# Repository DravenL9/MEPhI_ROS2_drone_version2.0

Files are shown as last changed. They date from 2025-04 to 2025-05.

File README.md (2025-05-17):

# MEPhI_ROS2_drone

**MEPhI_ROS2_drone** - это двухколесный робот с открытым исходным кодом, разработанный для образовательных целей командой студентов из НИЯУ МИФИ. MEPhI_ROS2_drone полностью интегрирован с ROS2 и является отличной базовой платформой для плавного введения в ROS2. Благодаря открытому коду и исходным файлам 3D моделей любой желающий может модифицировать и настроить робота в соответствии со своими требованиями.

*Данный проект является форком проекта [Andino](https://github.com/Ekumen-OS/andino), ПО, конструкция и электрическая схема которого были доработаны под наши требования.

<p align="center">
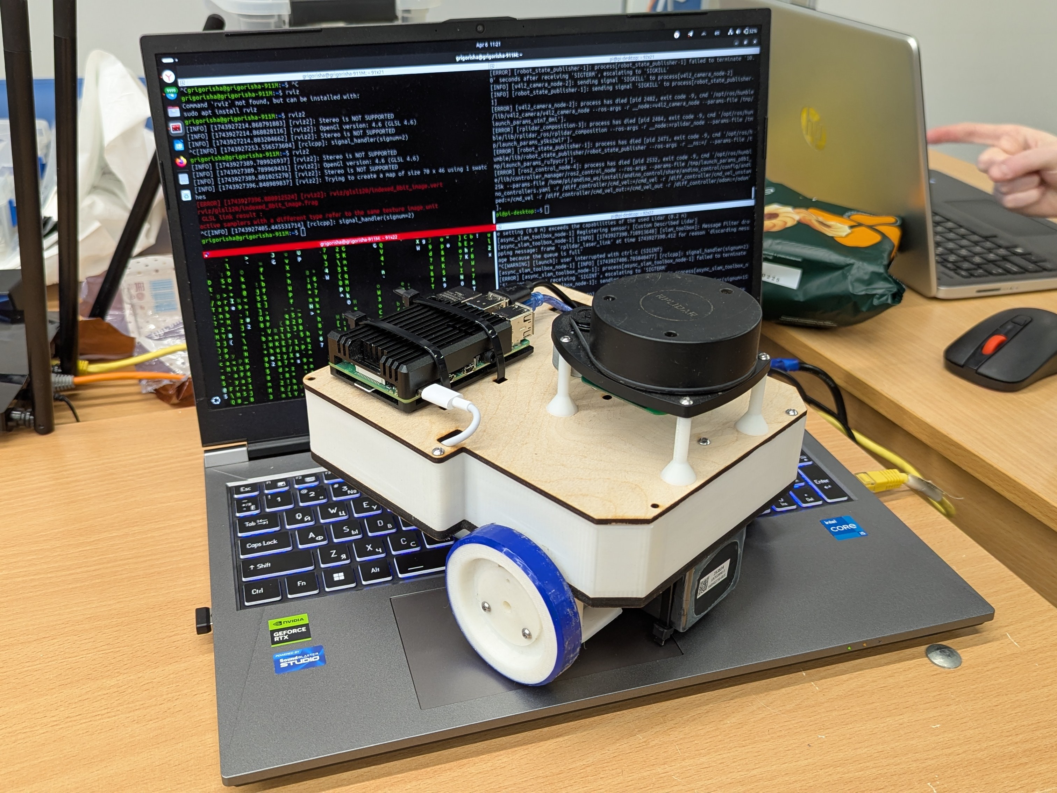
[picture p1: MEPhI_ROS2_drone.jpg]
  
</p>

## Описание проекта
- [`3D`](./3D): 3D модели деталей и сборки робота, также содержит `.stl` для 3D печати и `.dxf` для лазерной резки
- [`schematic`](./schematic): электрическая схема робота и инструкция по ее сборке
- [`MEPhI_ROS2_drone_hardware`](./andino_hardware): содержит инструкцию по сборке `MEPhI_ROS2_drone` и перечень используемого оборудования
- [`MEPhI_ROS2_drone_firmware`](./andino_firmware): содержит код отладочной платы Arduino UNO R3 для сопряжения с raspberry pi 4 и инструкцию по его заливке на плату
- [`MEPhI_ROS2_drone_bringup`](./andino_bringup): содержит файлы запуска для старта всех связанных драйверов и нод, которые будут использоваться в роботе
- [`MEPhI_ROS2_drone_description`](./andino_description): содержит описание робота в формате `.urdf`
- [`MEPhI_ROS2_drone_base`](./andino_base): это программно-аппаратный модуль проекта, который обеспечивает связь с микроконтроллером для управления моторами и предоставляет утилиты для отладки
- [`MEPhI_ROS2_drone_control`](./andino_control/): запускает [controller_manager](https://control.ros.org/humble/doc/ros2_control/controller_manager/doc/userdoc.html) вместе с [ros2 controllers](https://control.ros.org/master/doc/ros2_controllers/doc/controllers_index.html): [diff_drive_controller](https://control.ros.org/master/doc/ros2_controllers/diff_drive_controller/doc/userdoc.html) и [joint_state_broadcaster](https://control.ros.org/master/doc/ros2_controllers/joint_state_broadcaster/doc/userdoc.html)
- [`MEPhI_ROS2_drone_slam`](./andino_slam/): обеспечивает работу `SLAM` (одновременная локализация и построение карты)
- [`MEPhI_ROS2_drone_navigation`](./andino_navigation/): стек навигации, основанный на `Nav2`

## Видеоматериалы работы

### Отображение LaserScan в rviz2

LaserScan (https://youtu.be/dyld3nLJG04)

### Построение карты в ручном режиме

LaserScan (https://youtu.be/CHcgCHSs_-0)

### Автономное движение по карте

LaserScan (https://youtu.be/ocD7KzcdPOI)

## Сборка MEPhI_ROS2_drone

- Сборка конструкции робота подробно описана в [`andino_hardware`](./andino_hardware/)
- Сборка электрической схемы подробно описана в [`schematic`](./schematic/)

## Установка Ubuntu 22.04 на Raspberry Pi

Для работы MEPhI_ROS2_drone на Raspberry Pi 4B необходимо установить и настроить Ubuntu 22.04 LTS.

### Шаг 1: Загрузка и запись образа
1. Перейдите на сайт [https://ubuntu.com/download/raspberry-pi](https://ubuntu.com/download/raspberry-pi)
2. Выберете руководство по установке Ubuntu Desktop

### Шаг 2: Начальная настройка
1. Вставьте карту MicroSD в Raspberry Pi и подключите кабель питания USB-C 
2. Подключите монитор и клавиатуру
3. Проследуйте указаниям на экране
4. Запустите терминал и введите
```
sudo apt update && sudo apt upgrade -y
```
5. Проверьте версию Ubuntu (ожидаемый вывод: `Ubuntu 22.04 LTS`):
```
lsb_release -a
```
6. Проверьте подключение к интернету:
```
ping google.com
```

## Настройка USB портов

Назначьте фиксированные имена USB-портам для стабильного распознавания устройств в ROS2.

1. Подключите Arduino UNO R3 и RPLIDAR A1 к Raspberry Pi
2. Просмотрите подключенные USB-устройства:
```
ls -l /dev/ttyUSB*
```
Пример вывода:
```
crw-rw---- 1 root dialout 188, 0 Apr 06 03:10 /dev/ttyUSB0
crw-rw---- 1 root dialout 188, 1 Apr 06 03:10 /dev/ttyUSB1
```
3. Определите устройства:
 - Отключите RPLIDAR и снова выполните ls -l /dev/ttyUSB*. Исчезнувшее устройство — RPLIDAR
 - Повторите для Arduino
 - Пример: `/dev/ttyUSB0 = Arduino`, `/dev/ttyUSB1 = RPLIDAR`

4. Получите идентификаторы устройств:
```
udevadm info --name=/dev/ttyUSB0 --attribute-walk | grep -i "serial\|vendor"
```
Пример для Arduino:
```
ATTRS{serial}=="A1234567"
ATTRS{vendor}=="Arduino"
```
Пример для RPLIDAR:
```
ATTRS{serial}=="B7890123"
ATTRS{vendor}=="SLAMTEC"
```
5. Создайте правила udev:
 - Отредактируйте файл правил:
 ```
 sudo nano /etc/udev/rules.d/99-usb-serial.rules
 ```
 - Добавьте (замените serial на ваши значения):
```
SUBSYSTEM=="tty", ATTRS{serial}=="A1234567", SYMLINK+="ttyUSB_ARDUINO"
SUBSYSTEM=="tty", ATTRS{serial}=="B7890123", SYMLINK+="ttyUSB_LIDAR"
```
- Сохраните (Ctrl+O, Enter, Ctrl+X)

6. Перезагрузите правила:
```
sudo udevadm control --reload-rules
sudo udevadm trigger
```
7. Проверьте новые имена:
```
ls -l /dev/ttyUSB*
```
Ожидаемый вывод:
```
lrwxrwxrwx 1 root root 7 Apr 06 03:15 /dev/ttyUSB_ARDUINO -> ttyUSB0
lrwxrwxrwx 1 root root 7 Apr 06 03:15 /dev/ttyUSB_LIDAR -> ttyUSB1
```

## Прошивка отладочной платы Arduino UNO R3

Следуйте руководству в [`MEPhI_ROS2_drone_firmware`](./andino_firmware)

## Установка ROS2 Humble

### Шаг 1: Установка зависимостей
1. Настройте локализацию:
```
sudo apt update && sudo apt install -y locales
sudo locale-gen en_US en_US.UTF-8
sudo update-locale LC_ALL=en_US.UTF-8 LANG=en_US.UTF-8
export LANG=en_US.UTF-8
```
2. Добавьте репозиторий ROS2:
```
sudo apt install -y software-properties-common
sudo add-apt-repository universe
sudo apt update && sudo apt install -y curl gnupg lsb-release
sudo curl -sSL https://raw.githubusercontent.com/ros/rosdistro/master/ros.key -o /usr/share/keyrings/ros-archive-keyring.gpg
echo "deb [arch=$(dpkg --print-architecture) signed-by=/usr/share/keyrings/ros-archive-keyring.gpg] http://packages.ros.org/ros2/ubuntu $(lsb_release -cs) main" | sudo tee /etc/apt/sources.list.d/ros2.list > /dev/null
```
### Шаг 2: Установка ROS2
1. Установите ROS2 Humble Desktop:
```
sudo apt update
sudo apt install -y ros-humble-desktop
```
2. Установите инструменты разработки:
```
sudo apt install -y python3-colcon-common-extensions python3-rosdep python3-vcstool
```
3. Инициализируйте rosdep:
```
sudo rosdep init
rosdep update
```
4. Настройте окружение:
```
echo "source /opt/ros/humble/setup.bash" >> ~/.bashrc
source ~/.bashrc
```

## Сборка рабочего пространства MEPhI_ROS2_drone
### Шаг 1: Клонирование репозитория
1. Создайте рабочее пространство:
```
mkdir -p ~/MEPhI_ROS2_drone_ws/src
cd ~/MEPhI_ROS2_drone_ws/src
```
2. Склонируйте репозиторий:
```
git clone -b humble https://github.com/Muhamedli/MEPhI_ROS2_drone.git
```
### Шаг 2: Установка зависимостей
1. Установите зависимости ROS:
```
cd ~/MEPhI_ROS2_drone_ws
rosdep install --from-paths src --ignore-src -r -y
```
### Шаг 3: Сборка
1. Соберите проект:
```
colcon build
```
2. Подгрузите окружение:
```
echo "source ~/MEPhI_ROS2_drone_ws/install/setup.bash" >> ~/.bashrc
source ~/MEPhI_ROS2_drone_ws/install/setup.bash
```

## Настройка и запуск SLAM
SLAM позволяет роботу строить карту неизвестной среды и одновременно определять свое местоположение. В этом разделе используется пакет MEPhI_ROS2_drone_slam с алгоритмом Cartographer.

### Шаг 1: Запуск базовых нод
1. Запустите базовые ноды робота:
```
ros2 launch andino_bringup andino_robot.launch.py
```
Это активирует ноды для работы с двигателями и лидаром.

2. Проверьте доступные топики:
```
ros2 topic list
```
Ожидаемые топики:
- `/odom`: данные одометрии
- `/scan`: данные лидара

### Шаг 2: Запуск SLAM
1. Запустите SLAM:
```
ros2 launch andino_slam slam_toolbox_online_async.launch.py
```
2. Запустите rviz:
```
rviz2
```
3. Управляйте роботом для построения карты:
 - В новом терминале запустите телеуправление:
 ```
ros2 launch andino_bringup teleop_keyboard.launch.py
 ```
 - Используйте клавиши (исполнительные клавиши будут отображены на мониторе) для медленного перемещения робота по помещению

 ### Шаг 3: Сохранение карты
 1. Сохраните созданную карту:
 ```
 ros2 run nav2_map_server map_saver_cli -f ~/andino_map
 ```
 - Карта сохранится в файлах `andino_map.pgm` и `andino_map.yaml` в домашней директории
 2. Остановите SLAM:
 - Нажмите Ctrl+C в терминале с SLAM

 ### Шаг 4: Повторное использование карты
 1. Запустите навигацию с сохраненной картой:
 ```
 ros2 launch andino_navigation bringup.launch.py map:=~/andino_map.yaml
 ```
 2. Установите начальную позицию в RViz:
 - Используйте инструмент `2D Pose Estimate` в RViz
 - Щелкните на карте, чтобы указать приблизительное положение робота

 ## Устранение неполадок
 1. Лидар не работает:
 - Проверьте порт:
 ```
 ls -l /dev/ttyUSB_LIDAR
 ```
 - Убедитесь, что RPLIDAR подключен и питается
 2. Двигатели не реагируют:
 - Проверьте прошивку Arduino: отправьте `o 100 100` через Монитор порта
 - Убедитесь, что порт `/dev/ttyUSB_ARDUINO` доступен
 3. Карта не строится:
 - Проверьте топик /scan:
 ```
 ros2 topic echo /scan
 ```
 - Убедитесь, что робот движется и лидар собирает данные
 4. RViz не открывается:
 - Убедитесь, что RViz установлен:
 ```
 sudo apt install -y ros-humble-rviz2
 ```

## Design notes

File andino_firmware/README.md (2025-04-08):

# MEPhI_ROS2_drone_firmware

Здесь содержится прошивка для отладочной платы Arduino UNO R3. В файле [`Инструкция по прошивке отладочной платы Arduino UNO R3.pdf`](/andino_firmware/Инструкция%20по%20прошивке%20отладочной%20платы%20Arduino%20UNO%20R3.pdf) подробно описано как прошить плату.

## Отладочные команды

С помощью `Serial Monitor` в Arduino IDE при выставленной скорости `57600 baud` и режиме `Carriage return` можно отправлять отладочные команды на микроконтроллер и получать ответные данные (Arduino UNO R3 должна быть присоединена к USB порту вашего компьютера).

  - чтение статуса аналоговых пинов Arduino UNO R3: `a`
  - чтение статуса цифровых пинов Arduino UNO R3: `d`
  - чтение текущего положения энкодеров: `e`
  - сброс положения энкодеров в ноль: `r`
  - выставление скорости вращения колес в `тиках_энкодера/сек`: `m 5400 5400`
  - выставление скорости вращения колес заполнением ШИМ: `o 255 255`
  - задание коэффициентов PID регулятора: `u 1:2:3:4`
  - определение статуса IMU: `h`
  - чтение данных с IMU: `i`

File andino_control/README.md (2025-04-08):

# MEPhI_ROS2_drone_control

## Описание

Для управления роботом и взаимодействия с фреймворком ROS используется ROS2 Control.

Следующая диаграмма описывает основные компоненты системы, управляющей роботом с помощью инструментов ROS2 Control.

```mermaid
flowchart TD
    %% COLORS %%
    classDef blue fill:#2374f7,stroke:#000,stroke-width:2px,color:#fff
    classDef red fill:#ed2633,stroke:#000,stroke-width:2px,color:#fff
    classDef green fill:#16b522,stroke:#000,stroke-width:2px,color:#fff
    classDef orange fill:#fc822b,stroke:#000,stroke-width:2px,color:#fff

    %% DIAGRAM %%

    A(Diff Drive Controller):::blue ---|encoder read/velocity interface| B(Hardware Interface):::green
    C(Joint State Broadcaster):::blue ---|encoder read| B(Hardware Interface)

    M(Controller Manager):::orange -..->|manages lifecycle| A
    M(Controller Manager) -..-> |manages lifecycle| C
    M(Controller Manager) -..-> |activates hw component| B

    D["/cmd_vel"] -->|subs| A
    A -->|pubs| O["/odom"]
    A -->|pubs| T["/tf"]
    C -->|pubs| J["/joint_states"]

    linkStyle default stroke:red
    linkStyle 0 stroke-width:4px,stroke:green
    linkStyle 1 stroke-width:4px,stroke:green
    linkStyle 5 stroke:blue
```

### Hardware Interface

Компонент аппаратного интерфейса для этого робота реализован в пакете [`MEPhI_ROS2_drone_base`](/andino_base/). Он отвечает за предоставление необходимых интерфейсов состояния и команд, которые используются контроллерами.

### Controller Manager

[Controller Manager](https://control.ros.org/humble/doc/ros2_control/controller_manager/doc/userdoc.html#controller-manager) управляет жизненным циклом контроллеров, доступом к аппаратным интерфейсам и предоставляет сервисы для ROS.

Аппаратный интерфейс, который активируется при запуске узла `controller_manager`, указывается через описание робота, передаваемое через параметр ROS2. В описании робота должен присутствовать тег `<ros2_control>`, содержащий информацию о компонентах оборудования, а также интерфейсы состояния и команд. Смотреть [`andino_control.urdf.xacro`](../andino_description/urdf/include/andino_control.urdf.xacro).

### ROS2 Controllers

Используются два контроллера из библиотеки [ros2_controllers](https://control.ros.org/humble/doc/ros2_controllers/doc/controllers_index.html):

- [diff_drive_controller](https://control.ros.org/humble/doc/ros2_controllers/diff_drive_controller/doc/userdoc.html): контроллер для мобильных роботов с дифференциальным приводом. На вход принимает команды скорости движения робота, которые преобразуются в команды для колес. Одометрия вычисляется на основе данных с аппаратуры и публикуется.
  - Используемые интерфейсы состояния:
    - скорость левого колеса
    - скорость правого колеса
    - положение левого колеса
    - положение правого колеса
  - Используемые интерфейсы команд:
    - скорость левого колеса
    - скорость правого колеса
- [joint_state_broadcaster](https://control.ros.org/humble/doc/ros2_controllers/joint_state_broadcaster/doc/userdoc.html): считывает все интерфейсы состояния и публикует их в `/joint_states` и `/dynamic_joint_states`.
  - Используемые интерфейсы состояния:
    - положение левого колеса
    - положение правого колеса

Каждый контроллер принимает параметры ROS2, которые задаются в файле [`andino_controllers.yaml`](config/andino_controllers.yaml).

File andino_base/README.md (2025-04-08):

# MEPhI_ROS2_drone_base

## Описание

Взаимодействие аппаратного обеспечения, программного обеспечения и ROS в проекте `MEPhI_ROS2_drone` разработано с использованием [ROS 2 Control](https://control.ros.org/master/index.html).

Этот пакет:
 - Реализует hardware interface для MEPhI_ROS2_drone
 - Обеспечивает связь с микроконтроллером:
   - Класс `andino_base::MotorDriver` отвечает за последовательную связь для управления моторами
     - Предоставляется приложение для оценки связи: ознакомьтесь с `applications/motor_driver_demo.cpp`. Чтобы использовать это приложение, просто выполните `motor_driver_demo --help` для просмотра опций
   - Этот модуль связи используется в реализации аппаратного интерфейса

## Hardware Interface

В `ros2_control` компоненты аппаратной системы представляют собой библиотеки, динамически загружаемые менеджером контроллера с использованием интерфейса `pluginlib`.

Для получения дополнительной информации о компонентах оборудования см. [Hardware Components](https://control.ros.org/master/doc/getting_started/getting_started.html#overview-hardware-components).

Аппаратный интерфейс принимает некоторые параметры, которые передаются через описание urdf в теге `ros2_control` (см. [andino_description](../andino_description/urdf/include/andino_control.urdf.xacro)).

| Параметры | Описание |
|:--- | :----: |
| left_wheel_name | Название соединения левого колеса |
| right_wheel_name | Название соединения правого колеса |
| serial_device | Путь к последовательному устройству |
| baud_rate | Скорость передачи данных в бодах |
| timeout | Тайм-аут для связи |
| enc_ticks_per_rev | Количество тиков энкодера за один оборот колеса |

### State interfaces

Этот аппаратный интерфейс реализует следующие интерфейсы состояния для каждого соединения (для левого и правого соединения):
 - `Position`: позиция определяется на основе информации от энкодера, полученной от микроконтроллера
 - `Velocity`: скорость рассчитывается на основе информации от энкодера, полученной от микроконтроллера

### Command interfaces

Этот аппаратный интерфейс использует следующие командные интерфейсы для каждого соединения (для левого и правого соединения):
 - `Velocity`: полученная скорость (рад/с) преобразуется в номенклатуру скорости микроконтроллера для моторов

## Приложение Motor Driver

Для тестирования соединения с микроконтроллером предоставляется приложение.
После установки этого пакета можно использовать приложение под названием `motor_driver_demo`:
```
motor_driver_demo --help
```

Это приложение позволяет проверить связь с микроконтроллером для управления моторами. Команды для чтения энкодеров или индивидуальной установки скорости для моторов — это некоторые из возможностей.

## Примечания

`Последовательная связь`: если доступ к последовательному порту запрещен, вероятно, пользователя нужно добавить в группы `plugdev` и `dialout`:
 ```
sudo usermod -a -G dialout $USER
sudo usermod -a -G plugdev $USER
```

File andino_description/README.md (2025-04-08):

# MEPhI_ROS2_drone_description

## Описание
В папке `urdf` находятся файлы `.urdf`, содержащие описание робота, разделенные на разные модули и объединенные в файл `andino.urdf.xacro`.

## Конфигурация

Если вы хотите изменить физические свойства некоторых компонентов робота, вы можете сделать это, изменив файлы `.yaml`, хранящиеся по умолчанию в папке `config/andino`.

Вы даже можете добавить свои собственные конфигурационные файлы в другой каталог в папке `config` и передать этот каталог в основной файл, используя аргумент `yaml_config_dir` xacro в файлах запуска.

## Launch Files

Обычно используется при запуске робота для активации `robot state publisher` и заполнения статической информации `tf`, а также для предоставления описания робота:

```
ros2 launch andino_description andino_description.launch.py
```

Для запуска `robot state publisher` и предоставления визуализации с помощью `rviz` для анализа описания робота:
```
ros2 launch andino_description view_andino.launch.py
```

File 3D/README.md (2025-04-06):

- `3D модель MEPhI_ROS2_drone`: содержит исходные файлы 3D моделей деталей робота, спроектированные в САПР КОМПАС-3D v23.0.3.2285
- `DXF`: содержит файлы в формате `.dxf` для лазерной резки
- `STL`: содержит файлы в формате `.stl` для 3D печати

<p align="center">
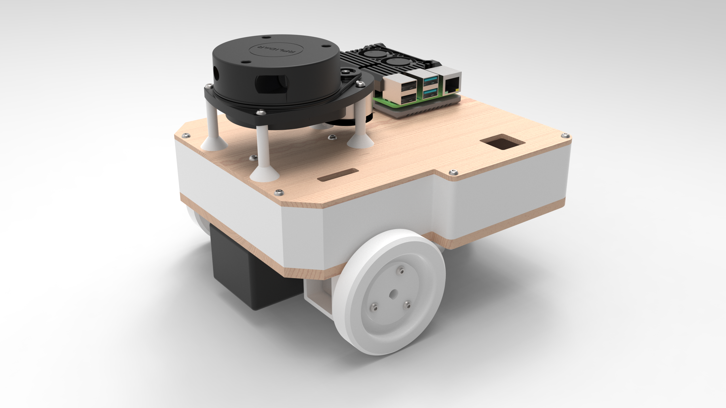
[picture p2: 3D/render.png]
  
</p>

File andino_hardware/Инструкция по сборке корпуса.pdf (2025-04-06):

Инструкция по сборке корпуса робота

### 1. Список стандартных изделий

1) Винт с полукруглой головкой и шестигранным углублением ГОСТ ISO 7380-1 - М3×10
2) Винт с полукруглой головкой и шестигранным углублением ГОСТ ISO 7380-1 - М3×12
3) Винт с полукруглой головкой и шестигранным углублением ГОСТ ISO 7380-1 - М3×16
4) Гайка М3 шестигранная оцинкованная

### 2. Сборка колесной конструкции

1) Крепление фланца к колесу
- Используйте 3 винта (2) для соединения фланца с колесом
- Зафиксируйте соединение гайками (4)

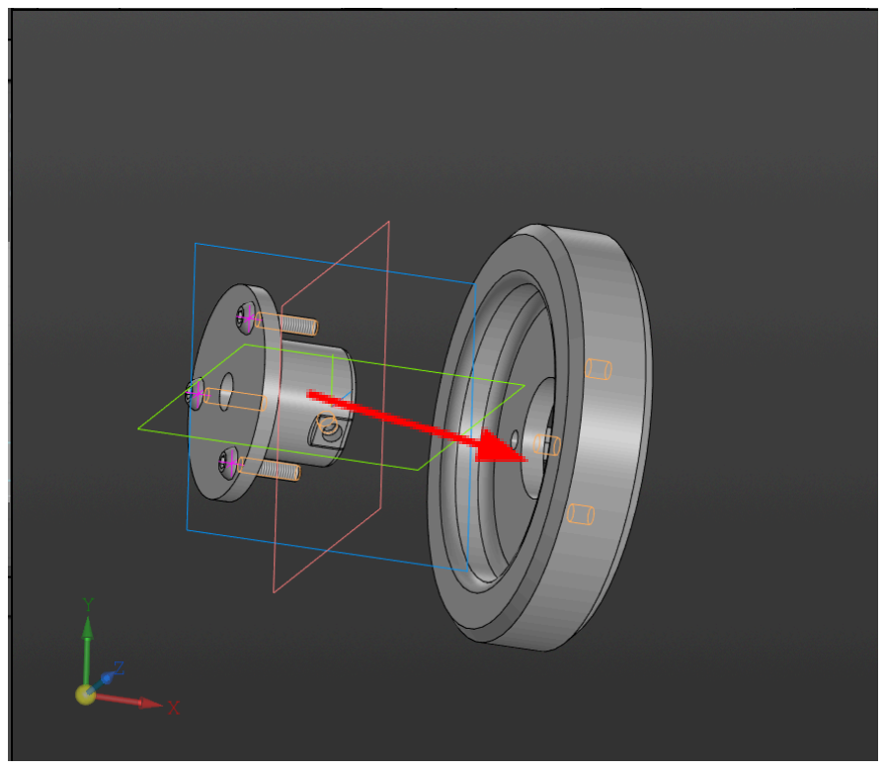
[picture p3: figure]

2) Установка оси мотора
- Вставьте гайку (3) в прямоугольное отверстие фланца
- Установите ось мотора во фланец
- Зафиксируйте ось винтом (4)

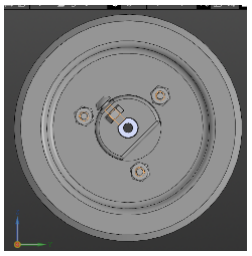
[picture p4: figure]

3) Крепление моторных скоб
- Наденьте правую скобу мотора на мотор
- Зафиксируйте мотор в скобе 1 винтом (2) и 2 винтами (3)
- Повторите для левой скобы

### 3. Сборка шаровой опоры

- Соедините шаровую опору с опорой для шаровой опоры 2 винтами (1)

### 4. Установка MPU 6050

- Закрепите MPU 6050 на опоре с помощью 2 винтов (3)

### 5. Сборка первого этажа

1) Крепление аккумулятора
- Закрепите аккумулятор 2 стяжками на первом этаже
- Расположите провода внутрь к отверстию
- Учтите асимметрию первого этажа.
Назовём сторону с мотором внешней, а противоположную — внутренней.

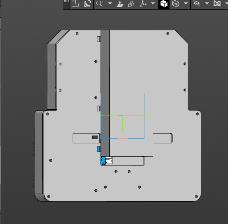
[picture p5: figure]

2) Монтаж моторных скоб

- Прикрепите левую и правую скобы мотора к внешней стороне 8 винтами (3) и 8 гайками (4)
3) Установка шаровой опоры
- Закрепите шаровую опору на внешней стороне 2 винтами (1)
4) Монтаж электроники
- На внутренней стороне зафиксируйте L298N Motor Driver 1 стяжкой.
- Установите MPU 6050, закрепив 2 гайками (4)
- Присоедините 2 стойки для Arduino 2 винтами (1)
- Установите Arduino Uno на стойки

### 6. Сборка второго этажа

1) Крепление Raspberry Pi 4
- Закрепите Raspberry Pi 4 стяжками
Сторона с Raspberry — внешняя, противоположная — внутренняя
2) Установка RPLidar

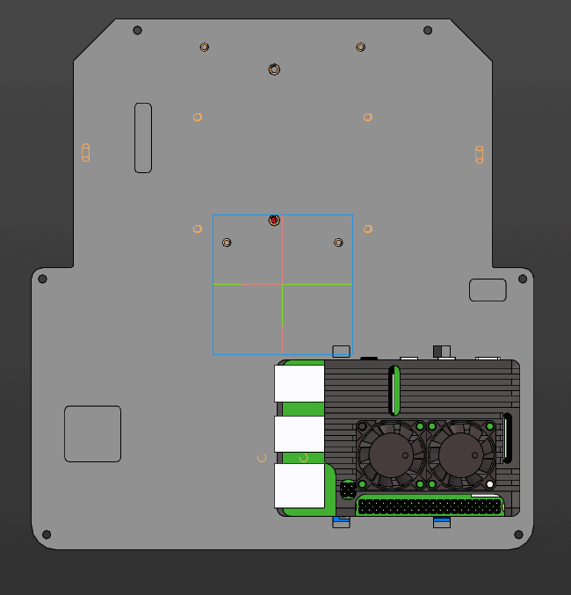
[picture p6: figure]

- Прикрепите 4 стойки для RPLidar к внешней стороне 4 винтами (1)
- Установите RP-lidar-A1, зафиксировав 4 винтами (1)
3) Монтаж понижающего преобразователя
- Закрепите преобразователь на внутренней стороне 2 винтами
(1) и 2 гайками (4)

### 7. Финальная сборка корпуса

1) Установка стенок
- Присоедините стенки корпуса к внутренней части первого этажа 6 винтами (1)
2) Соединение этажей
- Установите второй этаж на стенки корпуса, разместив преобразователь внутри корпуса

- Зафиксируйте соединение 6 винтами (1) Контроль качества
- Проверьте надежность всех креплений
- Убедитесь в отсутствии пережатых проводов
- Проверьте свободный ход колес
Сборка завершена!

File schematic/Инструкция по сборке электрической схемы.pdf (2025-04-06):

Инструкция по сборке электрической схемы робота

### 1. Компоненты

Для сборки схемы потребуются:
- Одноплатный компьютер Raspberry Pi 4B
- Микроконтроллер Arduino Uno
- Лидар RPLIDAR A1 M8
- Понижающий DC-DC преобразователь (5В, 4А, например, RCNUN WG8-60S0510)
- 2 мотора с энкодерами (датчиками, позволяющими отслеживать вращение вала мотора) JGY-370B
- Драйвер моторов L298N
- IMU-датчик GY-521 (MPU 6050) (трехосевой акселерометргироскоп)
- Аккумулятор 12В

### 2. Подготовка схемы

- Используйте принципиальную схему из приложенного файла.
- На схеме изображаются соединительные провода – зеленые линии, микросхемы – прямоугольники с соответствующими названиями и указанием выводов, аккумуляторная батарея на 12В, лидар, моторы и метки (NetLabel), используемые для избежания загромождения схемы.
- Большинство меток изображены в виде синих флажков с соответствующей подписью и подключенных к выводам микросхем. Метки (NetLabel) упрощают понимание соединений: ❖ GND — общая земля (все такие точки соединяются).
❖ +12V — плюсовая клемма аккумулятора.
- Все выводы микросхем, к которым подключены метки с одним и тем же названием, должны быть соединены соединительными проводами.
❖ Например, метка Motor_A_Vcc подсоединена к выводу драйвера мотора OUT1 и мотору Red_wire (Motor Vcc), и, как следствие, они должны быть соединены между собой проводом.
❖ “GND” же можно наблюдать на более, чем двух выводах: соединяем все выводы с соответствующей подписью между собой, образуя так называемую “общую землю”. Получаем параллельное соединение.

### 3. Питание компонентов

- Raspberry Pi 4B питается только от 5В (через USB Type-C). Подключите его к выходным проводам DC-DC преобразователя (5В). Нельзя питать Raspberry Pi 4B напряжением выше 5В!
- Arduino Uno питается через USB провод от Raspberry Pi, по которому одновременно идет питание и обмен данными.
- Лидар RPLIDAR A1 подключается к Raspberry Pi через USB провод, по которому одновременно идет питание и обмен данными.

### 4. Подключение моторов

- Драйвер L298N:
❖ Подключите +12V от аккумулятора к входу питания драйвера.
❖ Подключите моторы к выходам OUT1, OUT2 (Motor A) и OUT3, OUT4 (Motor B).
❖ Если моторы вращаются не в ту сторону — поменяйте полярность (Motor_A_Vcc и Motor_A_GND).
❖ Изменение полярности силовых проводов моторов (Motor_A_Vcc и Motor_A_GND) не приведут к выходу из строя используемых компонентов, но инвертируют направление вращение моторов. Данную ситуацию можно исправить программно, либо инвертировать подключение.
- Энкодеры моторов (4 провода: желтый, зеленый, черный, синий) подключите к Arduino Uno (цифровые пины).

### 5. Подключение датчиков

- IMU GY-521 подключите к Arduino Uno через I2C (SDA, SCL).
- 2 сигнала разрешения работы и 4 ШИМ-сигнала драйвера L298N (IN1, IN2, IN3, IN4, ENA, ENB) подключите к Arduino (ШИМпины).

### 6. Проверка и включение

- Проверьте на правильность все соединения по схеме (сверьте получившуюся схему с принципиальной).
- Не подключайте аккумулятор, пока не убедитесь в правильности сборки.
- Подключите аккумулятор 12В к:
❖ Входу DC-DC преобразователя (питание Raspberry Pi).
❖ Драйверу L298N (питание моторов).

### 7. Дополнительные рекомендации

- USB провода в своем составе имеют выводы “земли” и питания, поэтому дополнительных соединений не требуется.
- В схему на выходе с аккумуляторной батареи может быть добавлен тумблер включения общего питания.
- USB-порты Raspberry Pi для подключения лидара и микроконтроллера можно использовать любые.
- Ошибки подключения сигнальных (информационных) проводов приведут к некорректной работе собранного робота, но не приведут к выходу из строя компонентов.
- Ошибки в подключении силовых проводов (тех, по которым идет питание) могут привести к выходу из строя компонентов!

После проверки подайте питание и протестируйте систему. Удачи в сборке!

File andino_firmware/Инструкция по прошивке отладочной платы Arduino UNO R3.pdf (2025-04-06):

Инструкция по прошивке микроконтроллера

Одним из компонентов данного робота является отладочная плата Arduino UNO R3 на базе микроконтроллера ATmega328p. Для ее прошивки требуется выполнить следующие действия:

### 1. Подготовка программного обеспечения

- Скачайте Arduino IDE с официального сайта. (https://www.arduino.cc/en/software)

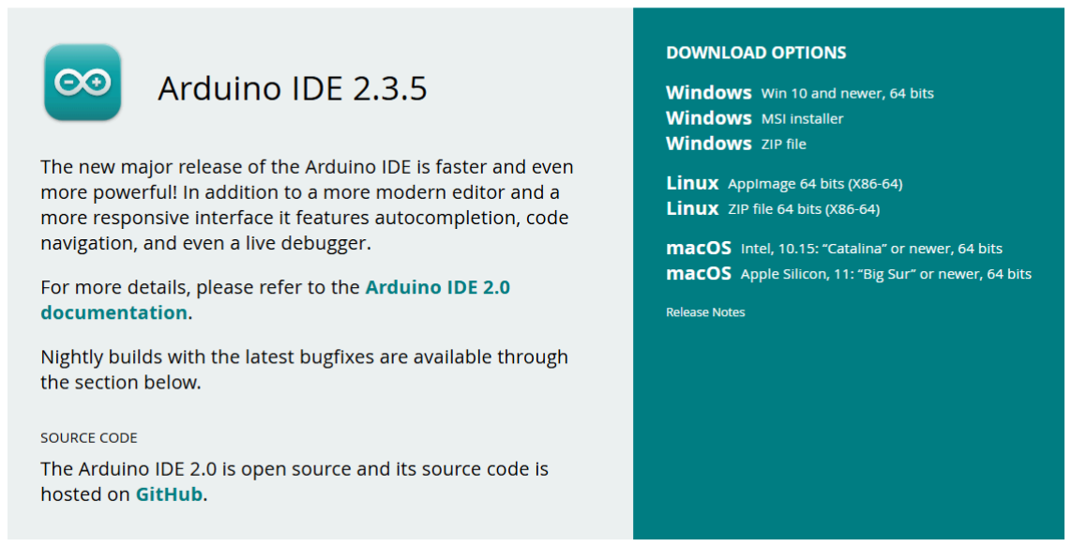
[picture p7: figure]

Рис. 1. Окно загрузки Arduino IDE.

- Установите программу, следуя инструкциям установщика.

### 2. Загрузка прошивки

- Клонируйте репозиторий с прошивкой:
git clone https://github.com/Muhamedli/MEPhI_ROS2_drone
- Откройте проект в Arduino IDE:
Файл → Открыть → выберите файл andino_firmware.ino из папки andino_firmware клонированного репозитория.

### 3. Установка библиотек

- В Arduino IDE перейдите:
Скетч → Подключить библиотеку → Управлять библиотеками....
- В строке поиска введите "Adafruit BNO055".
- Установите библиотеку от Adafruit, используя менеджер библиотек.

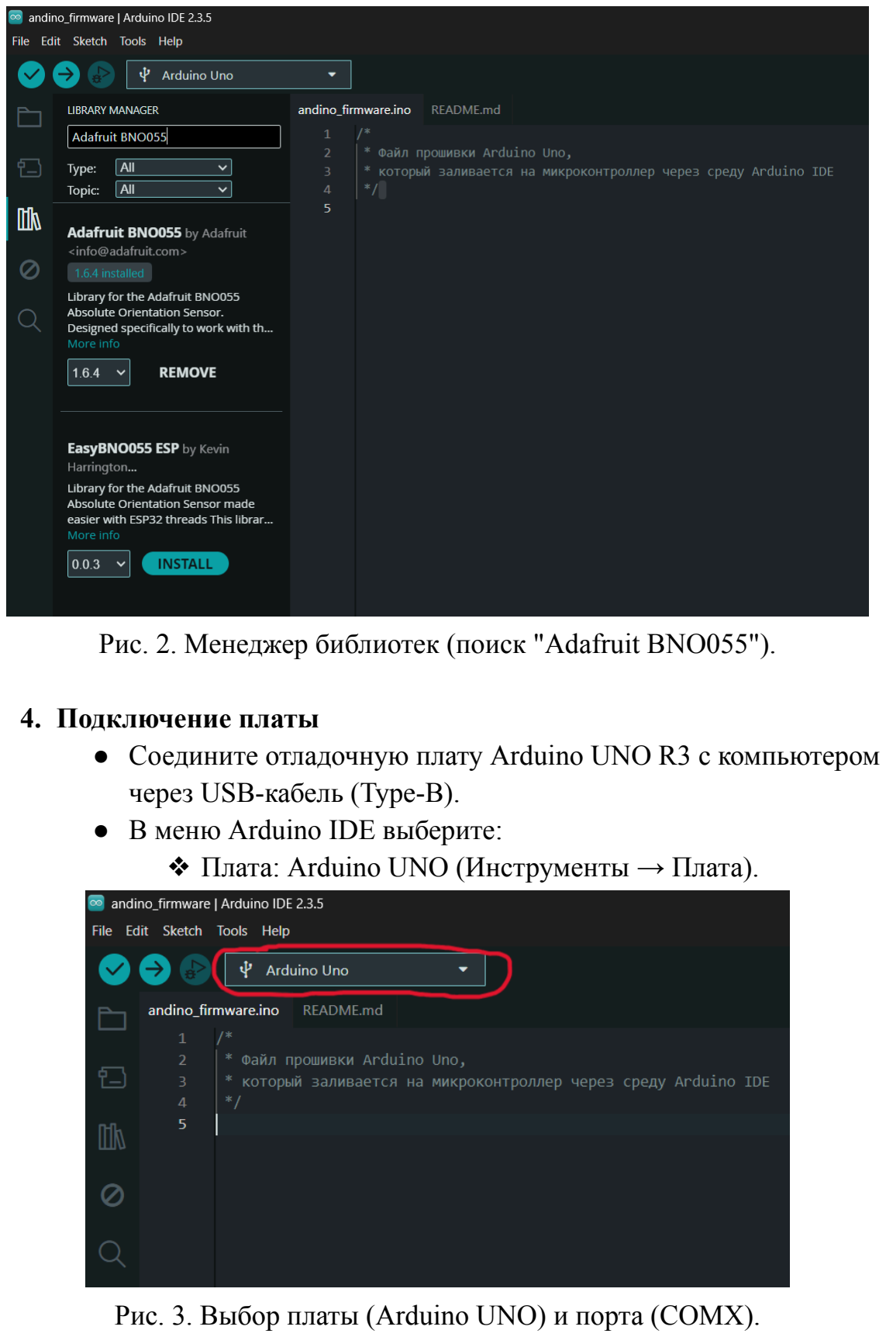
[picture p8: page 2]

Рис. 2. Менеджер библиотек (поиск "Adafruit BNO055").

### 4. Подключение платы

- Соедините отладочную плату Arduino UNO R3 с компьютером через USB-кабель (Type-B).
- В меню Arduino IDE выберите:
❖ Плата: Arduino UNO (Инструменты → Плата).

Рис. 3. Выбор платы (Arduino UNO) и порта (COMX).

❖ Соответствующий порт: COMX (где X — номер вашего порта, см. Инструменты → Порт).

### 5. Прошивка микроконтроллера

- Проверьте код (компиляция) (шаг 1 на рис. 4):
Нажмите ✔ (Verify) или Скетч → Проверить/Компилировать.
- Загрузите прошивку на отладочную плату Arduino UNO R3 (шаг 2 на рис. 4):
Нажмите → (Upload) или Скетч → Загрузить.

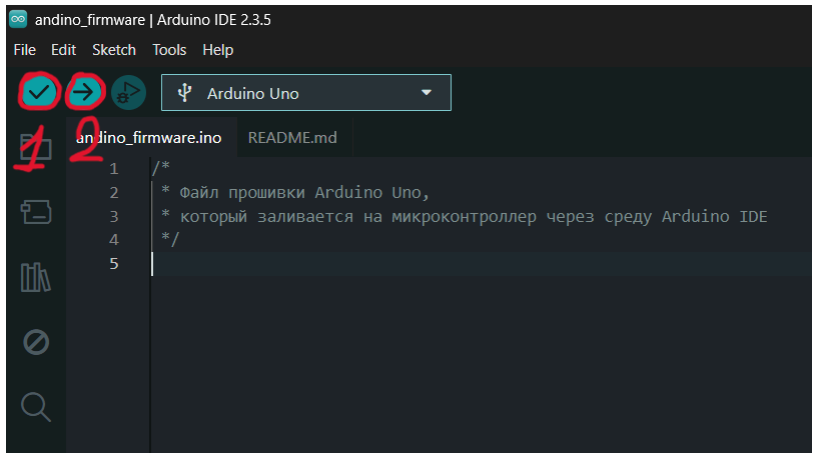
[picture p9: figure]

Рис. 4. Компиляция (1) и загрузка (2) программы.

### 6. Проверка работы

- После успешной загрузки (надпись "Загрузка завершена") плата готова к использованию.
- Если возникли ошибки, проверьте:
❖ Подключение кабеля.
❖ Выбор правильной платы и порта.
❖ Установленные библиотеки.

### 7. Дополнительно

- Для работы с датчиком BNO055 могут потребоваться дополнительные библиотеки (например, Adafruit_Sensor).
- Если используется клон Arduino, в менеджере плат можно добавить поддержку (например, CH340G).

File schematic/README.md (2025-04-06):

- `MEPhI_ROS2_drone_schematic.pdf`: содержит электрическую схему робота
- `Инструкция по сборке электрической схемы.pdf`: инструкция по сборке схемы

<p align="center">
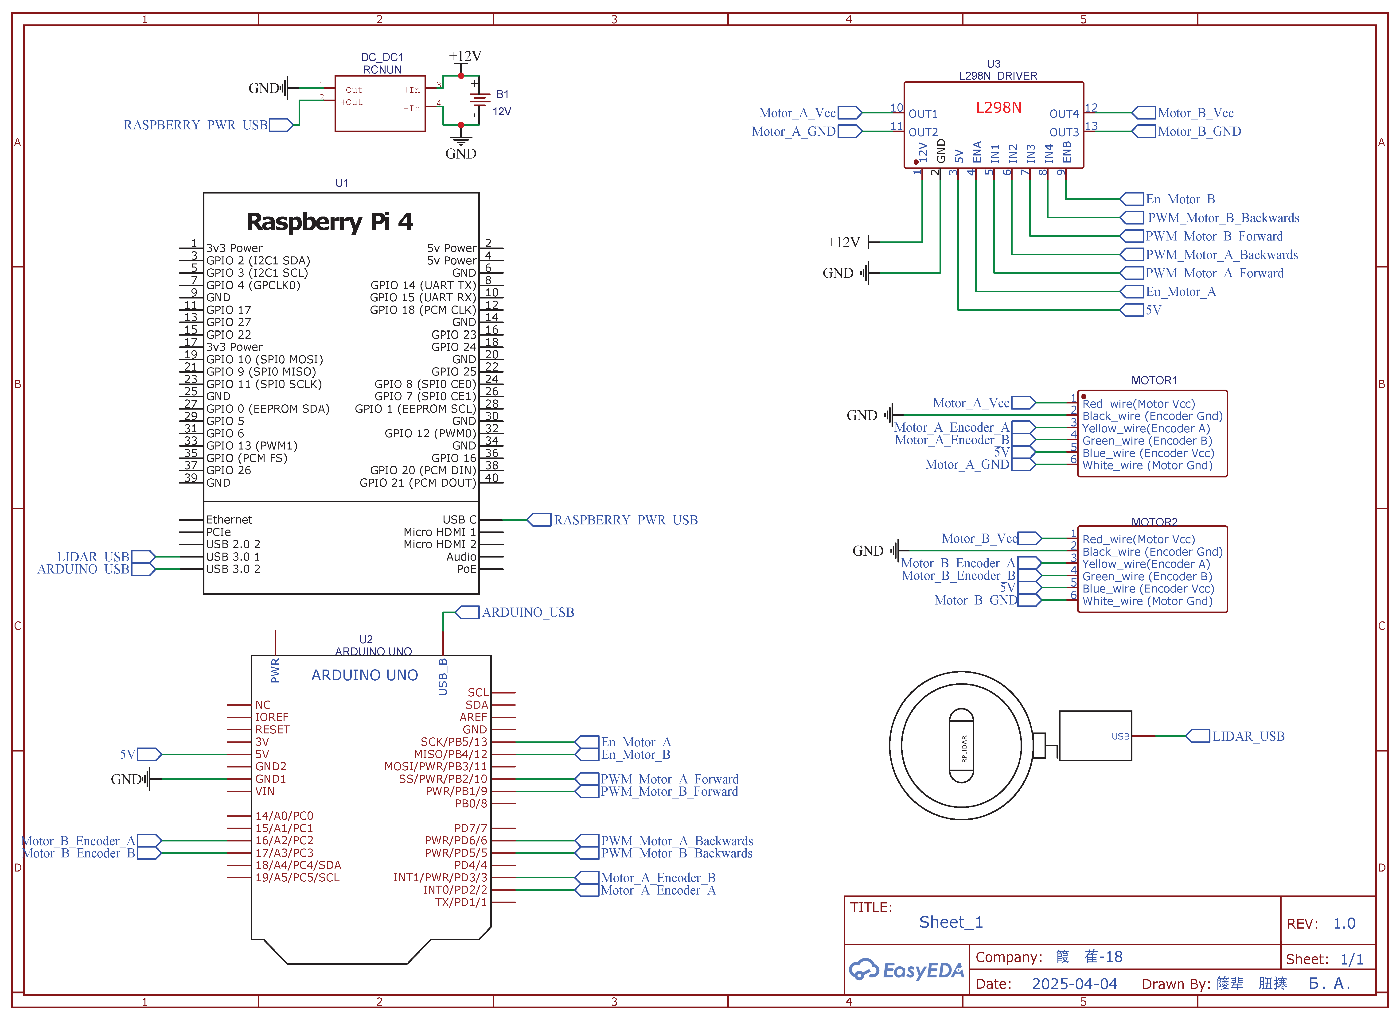
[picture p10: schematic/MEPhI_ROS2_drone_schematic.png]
  
</p>

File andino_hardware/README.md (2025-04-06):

# MEPhI_ROS2_drone_hardware

Здесь содержится инструкция по изготовлению деталей робота, инструкция по его сборке и список используемых компонентов.

## Перечень компонентов

| Название | Назначение  | Количество | Ссылка |
|---|---|---|---|
| Raspberry Pi 4 Model B 8GB | Управление моторами, датчиками и логикой; распознавание объектов, навигация; параллельная работа сенсоров, связи и алгоритмов; управление периферией; локальный сервер и облачная интеграция | 1 шт. | [ozon](https://www.google.com/url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)|
| Датчик-сканер Slamtec RPLIDAR A1 2D | Сканирует пространство (360°) для построения карты и навигации; помогает роботу ориентироваться в реальном времени | 1 шт. | [яндекс маркет](https://market.yandex.ru/product--skaner-slamtec-rplidar-a1-2d-360-gradusov-12-metrov/685634663?sku=103539320004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)|
| Понижающий DC-DC преобразователь RCNUN WG-48S1220 | Понижение напряжения; питание мощных модулей | 1 шт. |[яндекс маркет](https://market.yandex.ru/product--rcnun-ponizhaiushchii-modul-wg8-60s0510/1026632180?sku=103789709049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)|
| Аккумулятор LiPo Vant-11.1В 5200мАч 50C 3S1P | Питание | 1 шт. |[wildberries](https://www.wildberries.ru/catalog/143636070/detail.aspx)|
| Гироскоп и акселерометр MPU-6050 (GY-521) | Определение ориентации; стабилизация; инерциальная навигация | 1 шт. |[ozon](https://www.ozon.ru/product/giroskop-akselerometr-gy-521-arduino-mpu-6050-1142582502/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)|
| Драйвер шагового двигателя L298N | Управление двигателями; ШИМ-контроль | 1 шт. |[ozon](https://www.ozon.ru/product/drayver-shagovogo-shchetochnogo-dvigatelya-l298n-arduino-1592815273/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)|
| Мотор с редуктором и энкодером JGY-370B | Привод с контролем положения; точное управление | 1 шт. |[ozon](https://www.ozon.ru/product/motor-reduktor-jgy-370b-s-enkoderom-12v-90-ob-min-1688683559/?oos_search=false)|
| Плата контроллера Arduino Uno R3 (ATMega 328 / CH340G) | Микроконтроллер; среда разработки; работа с драйверами | 1 шт. |[ozon](https://www.ozon.ru/product/mikrokontroller-arduino-uno-r3-type-c-atmega328-lgt8f328-ch340-1548397969/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)|
| Винт ISO 7380 А2 М3х10 с полукруглой головкой | Крепежное изделие | 50 шт. |[ozon](https://www.ozon.ru/product/vint-iso-7380-a2-m3h10-s-polukrugloy-golovkoy-nerzhaveyka-50-sht-1309301713/)|
| Винт ISO 7380 А2 М3х8 с полукруглой головкой  | Крепежное изделие | 20 шт. |[ozon](https://www.ozon.ru/product/vint-iso-7380-a2-m3h8-s-polukrugloy-golovkoy-nerzhaveyka-20-sht-1309302016/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)|
| Винт ISO 7380 А2 М3х16 с полукруглой головкой | Крепежное изделие | 10 шт. |[ozon](https://www.ozon.ru/product/vint-iso-7380-a2-m3h16-s-polukrugloy-golovkoy-nerzhaveyka-10-sht-1088287603/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)|
| Гайка М3 шестигранная оцинкованная | Крепежное изделие | 200 шт. |[ozon](https://www.ozon.ru/product/gayka-m3-shestigrannaya-200-sht-otsinkovannaya-1706097449/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гайка+м3)|
| Стяжка (хомут) нейлоновая пластиковая | Крепежное изделие | 100 шт. |[ozon](https://www.ozon.ru/product/styazhka-homut-neylonovaya-plastikovaya-krepezh-2-5h200mm-1045860514/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)|
| Универсальное опорное колесо с нейлоновым шаром | Опорное изделие | 1 шт. |[амперкот](https://amperkot.ru/msk/catalog/universalnoe_opornoe_koleso_s_neylonovyim_sharom_1587_mm-39388352.html)|
| Соединительные провода Dupont (Папа-мама) | Межкомпонентное соединение | 40 шт. |[амперкот](https://amperkot.ru/msk/catalog/soedinitelnyie_provoda_dupont__papamama_40sht_raznotsvetnyie_30_sm-23875248.html)|
| Металлические стойки для крепления материнской платы | Крепежное изделие | 10 шт. |[ozon](https://www.ozon.ru/product/metallicheskie-prostavki-stoyki-dlya-krepleniya-materinskoy-platy-shestigrannyy-krepezh-m3-7-1020282755/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стойка+м3%2A7)|

## Изготовление деталей
[`Изготовление деталей.pdf`](/andino_hardware/Изготовление%20деталей.pdf): инструкция по 3D печати и лазерной резке

Файлы деталей содержатся в [`3D`](/3D/)

## Сборка робота
[`Инструкция по сборке корпуса.pdf`](/andino_hardware/Инструкция%20по%20сборке%20корпуса.pdf): инструкция по сборке корпуса

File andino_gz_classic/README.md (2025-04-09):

# Симуляция робота MEPhI_ROS2_drone в Gazebo

## Сборка

Установите зависимости пакетов:

```
rosdep install --from-paths src -i -y
```

Создайте пакет:

```
colcon build
```

Примечание: `--symlink-install` при необходимости может быть добавлен.

Наконец, создайте исходную папку установки:

```
. install/setup.bash
```

Примечание: `gazebo` возможно, потребуется найти источник:

```
. /usr/share/gazebo/setup.bash
```

# Использование 

## MEPhI_ROS2_drone симуляция с плагином Gazebo diff drive

```
ros2 launch andino_gz_classic andino_one_robot.launch.py initial_pose_x:=3.0
```

Этот файл запуска поддерживает следующие параметры запуска:

- `use_sim_time`: этот параметр указывает rviz, что он должен работать со временем моделирования (по умолчанию: `true`)
- `rviz`: этот параметр позволяет определить, хотите ли вы запускать rviz при этом запуске. Значение `False` может быть полезно, если вы хотите просмотреть rviz на другом компьютере (по умолчанию: `true`)
- `world`: SDF-файл мира, в котором будет запущен MEPhI_ROS2_drone. Обратите внимание, что мир должен быть доступен в `gazebo paths` (по умолчанию: `empty_world.world`)

Наконец, доступны все параметры запуска MEPhI_ROS2_drone для перевода робота в определенное положение. Для получения дополнительной информации обо всех параметрах дочерних файлов запуска вы можете написать:
```
ros2 launch andino_gz_classic andino_one_robot.launch.py -s
```

## MEPhI_ROS2_drone симуляция с плагином Gazebo ros2 control

```
ros2 launch andino_gz_classic andino_one_robot.launch.py use_gazebo_ros_control:=true
```

## Создание MEPhI_ROS2_drone robot

```
ros2 launch andino_gz_classic spawn_robot.launch.py initial_pose_x:=3.0 entity:=andino robot_description_topic:=/andino/robot_description
```

Параметры этого запуска позволяют поместить робота в любое место симуляции.

- `use_sim_time`: используйте часы моделирования (Gazebo), если значение `true` (по умолчанию: `true`)

- `initial_pose_x`: начальная x-поза MEPhI_ROS2_drone в моделировании (по умолчанию: `0.0`)

- `initial_pose_y`: начальная y-поза MEPhI_ROS2_drone в моделировании (по умолчанию: `0.0`)

- `initial_pose_z`: начальная z-поза MEPhI_ROS2_drone в моделировании (по умолчанию: `0.0`)

- `robot_description_topic`: топик с описанием робота (по умолчанию: `/robot_description`)

- `initial_pose_yaw`: начальная yaw-поза (угол рыскания) MEPhI_ROS2_drone в моделировании (по умолчанию: `0.0`)

- `use_gazebo_ros_control`: значение `True` для использования плагина `gazebo_ros_control` (по умолчанию: `false`)

- `entity`: имя робота (по умолчанию: `MEPhI_ROS2_drone`)

- `rsp_frequency`: частота публикации состояния робота (по умолчанию: `30.0`)

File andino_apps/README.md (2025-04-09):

# MEPhI_ROS2_drone Apps

Этот пакет содержит приложения для работы с MEPhI_ROS2_drone.

# Приложения

## Gazebo classic simulation + Nav2

Файл для запуска и моделирования MEPhI_ROS2_drone_gz_classic и стека Nav2. По умолчанию используется мир [`turtlebot3_world`](https://github.com/ROBOTIS-GIT/turtlebot3_simulations/tree/master).

```
 ros2 launch andino_apps andino_simulation_navigation.launch.py
```

Для визуализации робота MEPhI_ROS2_drone и взаимодействия с ним в `RViz`:

- Нажмите кнопку `2D Pose Estimate` и выберите начальную позу робота
- Нажмите кнопку `2D Goal Pose` и выберите конечную точку

Робот начнет двигаться к выбранной цели.

Rviz_example_Nav2

Для получения дополнительной информации и примеров вы можете ознакомиться с [Nav2 tutorials](https://docs.nav2.org/tutorials/index.html).

Изменяя файл world, не забудьте также изменить файл map.

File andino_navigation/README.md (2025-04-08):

# MEPhI_ROS2_drone Navigation

Мы полагаемся на стек [Nav2](https://github.com/ros-planning/navigation2) для навигации MEPhI_ROS2_drone.

# Использование

## Предварительные требования
  1. Запустите основной стек на MEPhI_ROS2_drone:

```
ros2 launch andino_bringup andino_robot.launch.py
```

  2. Запишите карту с помощью [`MEPhI_ROS2_drone_slam`](../andino_slam/README.md).

## Run Nav Stack

Запустите стек навигации командой:

```
ros2 launch andino_navigation bringup.launch.py map:=<path-to-my-map-yaml-file>
```

По умолчанию используется [config file](params/nav2_params.yaml). Для использования пользовательского файла параметров выполните:

```
ros2 launch andino_navigation bringup.launch.py map:=<path-to-my-map-yaml-file> params_file:=<path-to-my-param-file>
```

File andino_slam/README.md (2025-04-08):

# MEPhI_ROS2_drone_slam

## Описание

Для запуска SLAM мы полагаемся на замечательный пакет [`slam_toolbox`](https://github.com/SteveMacenski/slam_toolbox/tree/ros2).

## Использование

После запуска робота просто запустите файл запуска SLAM:
```
ros2 launch andino_slam slam_toolbox_online_async.launch.py
```

Несколько конфигураций могут быть перенаправлены в `slam_toolbox_node`. По умолчанию параметры конфигурации получены из [config/slam_toolbox_only_async.yaml](config/slam_toolbox_online_async.yaml). В случае, если требуется передать пользовательский файл, просто используйте аргумент launch file для указания пути к новому файлу:

```
ros2 launch andino_slam slam_toolbox_online_async.launch.py slams_param_file:=<my_path>
```

Для сохранения карты вы можете использовать узел `map_saver_cli`, предоставляемый Nav2:

```
ros2 run nav2_map_server map_saver_cli -f <my-map-name>
```

Вы можете изменить пороговое значение для свободного пространства (0.25) и занятого пространства (0.65), используя аргументы
`--free` и `--occ`:

```
ros2 run nav2_map_server map_saver_cli --free 0.15 -f <my-map-name>
```

Больше информации тут:
 - https://github.com/ros-planning/navigation2/tree/main/nav2_map_server

Сохранив карту, вы сможете перемещаться по ней! Перейдите на страницу [`MEPhI_ROS2_drone_navigation`](../andino_navigation/README.md), чтобы узнать, как это сделать.

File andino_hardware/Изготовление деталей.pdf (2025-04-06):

Инструкция по изготовлению деталей для робота

### 1. Детали для 3D-печати

Необходимо изготовить:
- Стенка корпуса — 1 шт.
- Колесо — 2 шт.
- Фланец — 2 шт.
- Скоба мотора левая — 1 шт.
- Скоба мотора правая — 1 шт.
- Стойка для RPLidar — 1 шт.
- Опора для шаровой опоры — 1 шт.
- Опора для MPU 6050 — 1 шт.

### 2. Рекомендуемые настройки 3D-печати

Параметр | Значение
Материал | PLA пластик
Диаметр сопла | 0.4 мм
Высота слоя | 0.2 мм
Температура сопла | 205 °C
Скорость печати | 60 мм/с
Скорость 1-го слоя | 30 мм/с
Заполнение | 20%
Толщина стенок | 4 периметра
Толщина крышки/дна | 4 слоя
Прилипание к столу | Кайма

Рекомендуется включить поддержки в следующих деталях:
- Колесо
- Скоба мотора левая
- Скоба мотора правая

### 3. Постобработка 3D-деталей

- Дождитесь остывания стола и сопла принтера.
- Аккуратно снимите детали шпателем.
- Удалите поддержки пассатижами и кусачками с напечатанных деталей.

### 4. Лазерная резка фанеры

Следующие детали необходимо вырезать на лазерном станке ЧПУ для резки фанеры с использованием соответствующих настроек

Настройки для станка (мощность лазера 100 Вт):
Деталь | Материал | Толщина | Скорость резания | Мощность лазера
Первый этаж | Фанера | 6 мм | 11 мм/с | 70%
Второй этаж | Фанера | 3 мм | 18 мм/с | 60%

Постобработка:
- После окончания резки и выключения станка рекомендуется протереть края резки от нагара, выделившегося в ходе выполнения резания.

### 5. Контроль качества:

- Убедитесь в отсутствии деформаций и заусенцев.

Готово! Детали подготовлены для сборки.

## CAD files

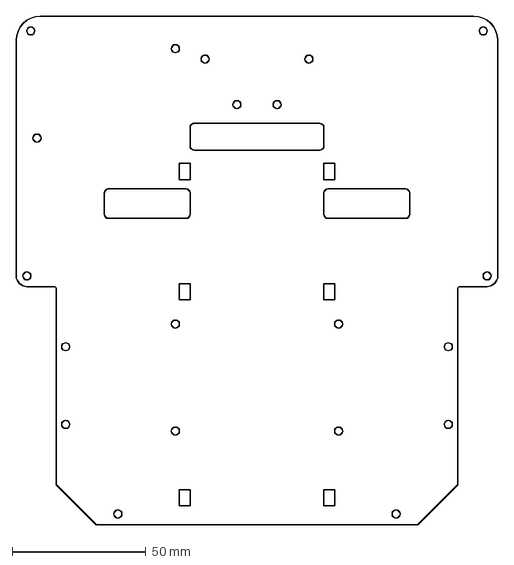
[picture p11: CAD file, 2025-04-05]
3D/DXF/6mm_base_1.dxf
180.0 x 190.0 mm

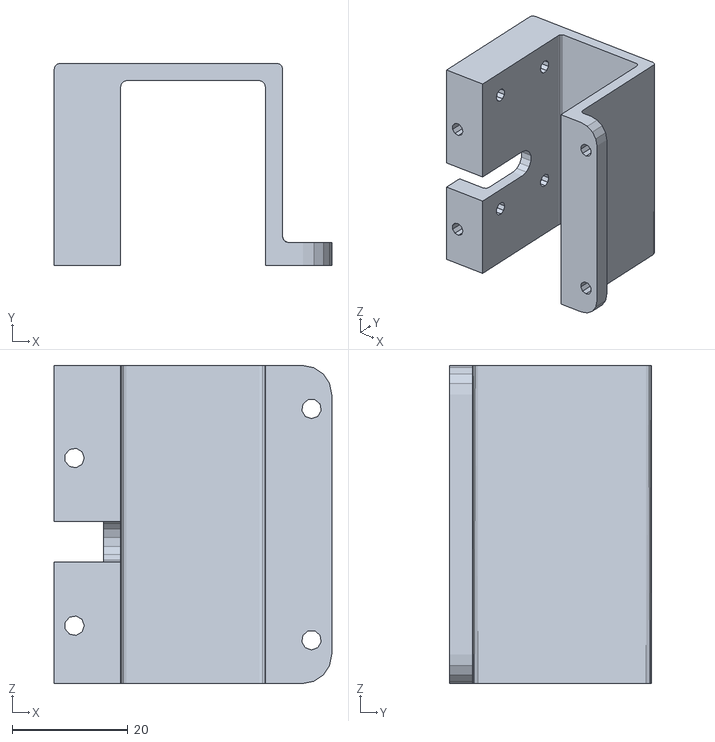
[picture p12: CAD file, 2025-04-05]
3D/STL/1-PLA-20%-Cкоба мотора левая.stl
48.0 x 35.0 x 55.0

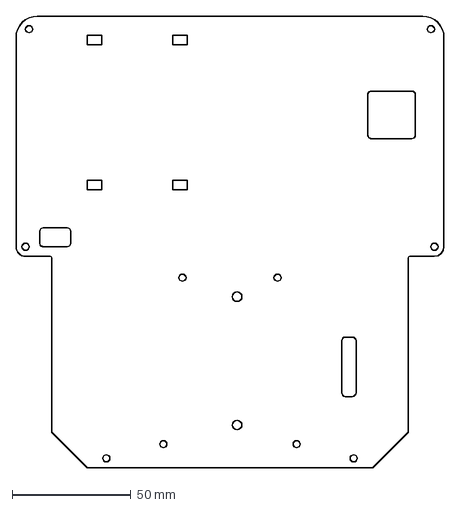
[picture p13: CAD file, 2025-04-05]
3D/DXF/3mm_base_2.dxf
180.0 x 190.0 mm

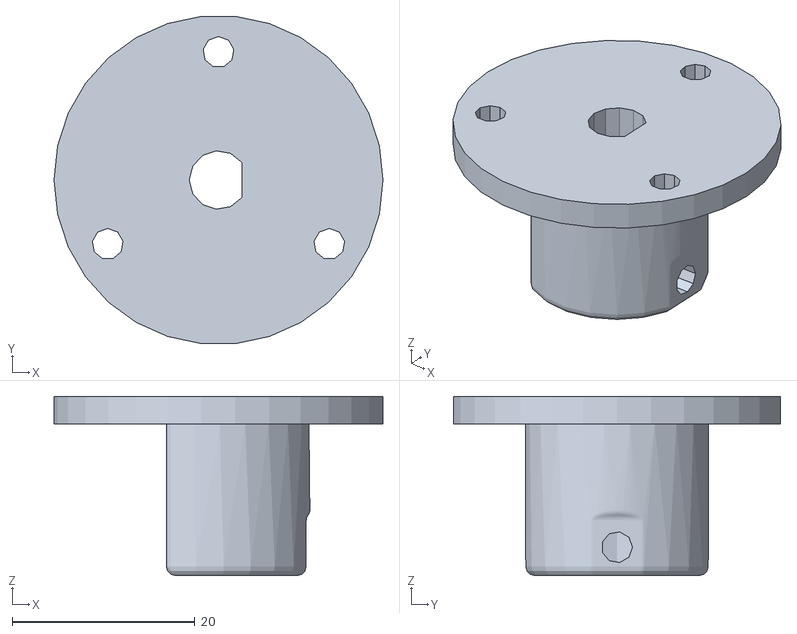
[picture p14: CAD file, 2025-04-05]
3D/STL/2-PLA-20%-Фланец.stl
36.0 x 35.8 x 19.6

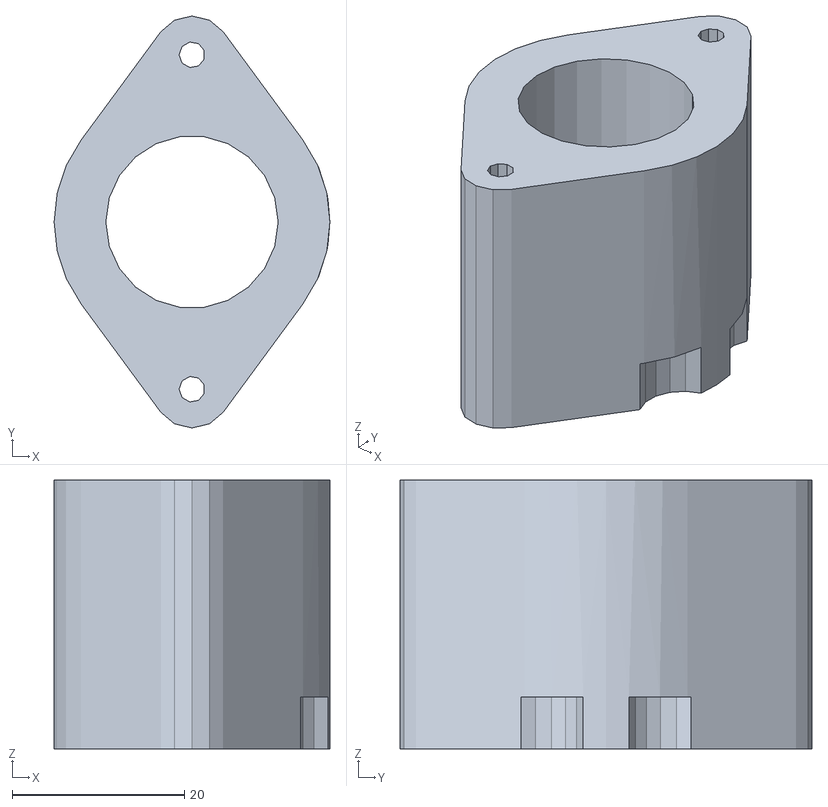
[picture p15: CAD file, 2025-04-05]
3D/STL/1-PLA-20%-Опора для шаровой опоры.stl
32.0 x 47.8 x 31.2

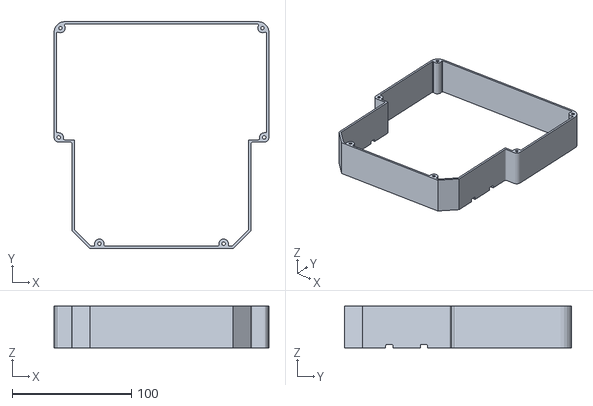
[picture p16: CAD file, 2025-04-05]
3D/STL/1-PLA-20%-Стенки корпуса.stl
180.0 x 190.0 x 35.0

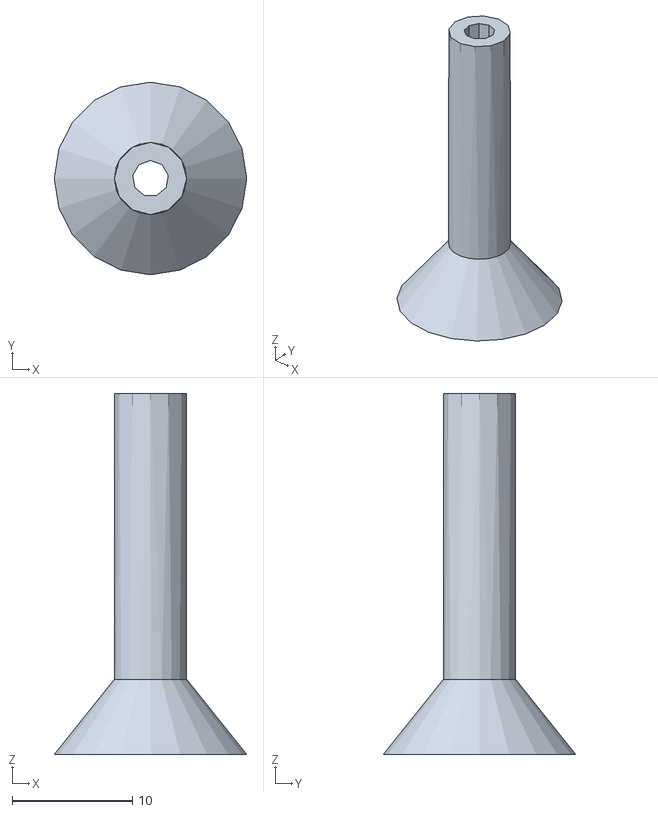
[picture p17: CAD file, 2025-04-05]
3D/STL/4-PLA-20%-Стойка для RPLidar.stl
16.0 x 16.0 x 30.0

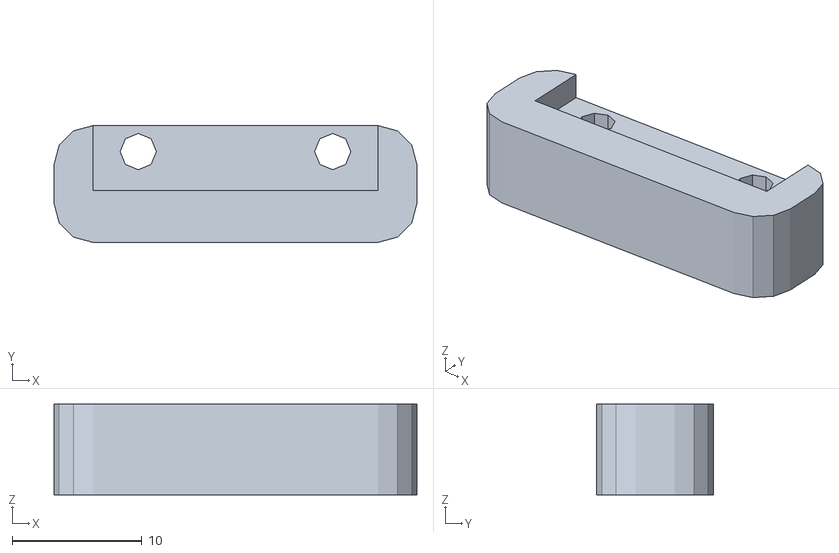
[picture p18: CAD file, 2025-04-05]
3D/STL/1-PLA-20%-Опора для MPU 6050.stl
28.0 x 9.00 x 7.00

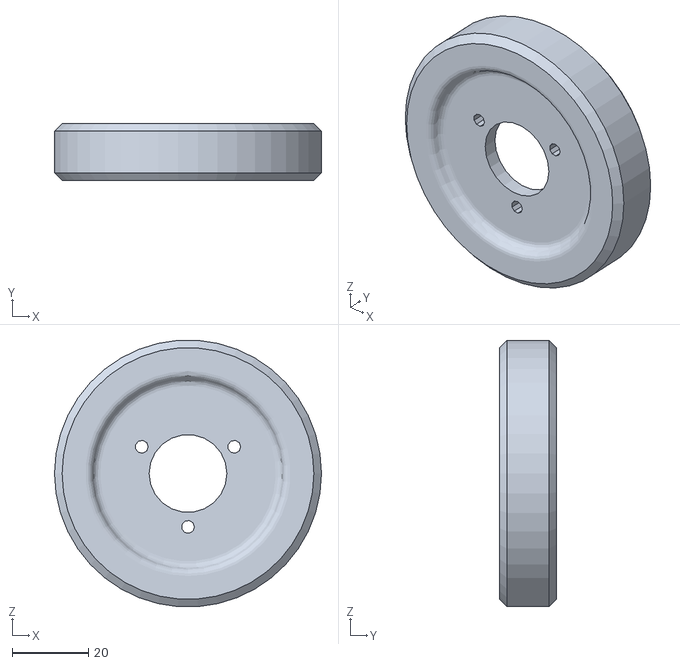
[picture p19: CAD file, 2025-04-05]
3D/STL/2-PLA-20%-Колесо.stl
70.0 x 15.0 x 69.8

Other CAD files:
3D/STL/1-PLA-20%-Скоба мотора правая.stl

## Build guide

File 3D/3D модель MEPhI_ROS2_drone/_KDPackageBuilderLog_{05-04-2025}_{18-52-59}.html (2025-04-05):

# Отчет о комплектовке

Дата и время выполнения: 05.04.2025 18:53

Версия КОМПАС-Invisible: 23.0.0.2180

### Результаты комплектовки:

Комплектовка завершена успешно

Затраченное время: 0 ч 1 мин 35 с

Файлов в комплекте: 97

Не удалось добавить в комплект следующие файлы (всего 0):

### Файлы КОМПАС-документов, добавленные в комплект:

Исходное имя | Имя в комплекте
C:\Program Files\ASCON\KOMPAS-3D v23\Libs\PolynomLib\DATA\vault\Methods\Kompas\3D\PLib_Nut_OST92_900.m3d | C:\Users\пользователь\Desktop\работа\хахатон\итог\комплект файлов (комплектовщик Компас-3D + STEP сборка)\_3D\PLib_Nut_OST92_900.m3d
C:\Program Files\ASCON\KOMPAS-3D v23\Libs\PolynomLib\DATA\vault\Methods\Kompas\3D\PLib_Screw_ISO_7380_1500.m3d | C:\Users\пользователь\Desktop\работа\хахатон\итог\комплект файлов (комплектовщик Компас-3D + STEP сборка)\_3D\PLib_Screw_ISO_7380_1500.m3d
C:\Users\пользователь\Desktop\работа\хахатон\_KDPackageArchive_{02-04-2025}_{01-15-20}\комплектующие\Arduino\arduinoUnoCH340_USB-B_v2.a3d | C:\Users\пользователь\Desktop\работа\хахатон\итог\комплект файлов (комплектовщик Компас-3D + STEP сборка)\комплектующие\Arduino\arduinoUnoCH340_USB-B_v2.a3d
C:\Users\пользователь\Desktop\работа\хахатон\_KDPackageArchive_{02-04-2025}_{01-15-20}\комплектующие\Arduino\arduinoUnoCH340_USB-B_v2_1.a3d | C:\Users\пользователь\Desktop\работа\хахатон\итог\комплект файлов (комплектовщик Компас-3D + STEP сборка)\комплектующие\Arduino\arduinoUnoCH340_USB-B_v2_1.a3d
C:\Users\пользователь\Desktop\работа\хахатон\_KDPackageArchive_{02-04-2025}_{01-15-20}\комплектующие\Arduino\arduinoUnoCH340_USB-B_v2_10.a3d | C:\Users\пользователь\Desktop\работа\хахатон\итог\комплект файлов (комплектовщик Компас-3D + STEP сборка)\комплектующие\Arduino\arduinoUnoCH340_USB-B_v2_10.a3d
C:\Users\пользователь\Desktop\работа\хахатон\_KDPackageArchive_{02-04-2025}_{01-15-20}\комплектующие\Arduino\arduinoUnoCH340_USB-B_v2_11.a3d | C:\Users\пользователь\Desktop\работа\хахатон\итог\комплект файлов (комплектовщик Компас-3D + STEP сборка)\комплектующие\Arduino\arduinoUnoCH340_USB-B_v2_11.a3d
C:\Users\пользователь\Desktop\работа\хахатон\_KDPackageArchive_{02-04-2025}_{01-15-20}\комплектующие\Arduino\arduinoUnoCH340_USB-B_v2_12.a3d | C:\Users\пользователь\Desktop\работа\хахатон\итог\комплект файлов (комплектовщик Компас-3D + STEP сборка)\комплектующие\Arduino\arduinoUnoCH340_USB-B_v2_12.a3d
C:\Users\пользователь\Desktop\работа\хахатон\_KDPackageArchive_{02-04-2025}_{01-15-20}\комплектующие\Arduino\arduinoUnoCH340_USB-B_v2_13.a3d | C:\Users\пользователь\Desktop\работа\хахатон\итог\комплект файлов (комплектовщик Компас-3D + STEP сборка)\комплектующие\Arduino\arduinoUnoCH340_USB-B_v2_13.a3d
C:\Users\пользователь\Desktop\работа\хахатон\_KDPackageArchive_{02-04-2025}_{01-15-20}\комплектующие\Arduino\arduinoUnoCH340_USB-B_v2_14.a3d | C:\Users\пользователь\Desktop\работа\хахатон\итог\комплект файлов (комплектовщик Компас-3D + STEP сборка)\комплектующие\Arduino\arduinoUnoCH340_USB-B_v2_14.a3d
C:\Users\пользователь\Desktop\работа\хахатон\_KDPackageArchive_{02-04-2025}_{01-15-20}\комплектующие\Arduino\arduinoUnoCH340_USB-B_v2_15.a3d | C:\Users\пользователь\Desktop\работа\хахатон\итог\комплект файлов (комплектовщик Компас-3D + STEP сборка)\комплектующие\Arduino\arduinoUnoCH340_USB-B_v2_15.a3d
C:\Users\пользователь\Desktop\работа\хахатон\_KDPackageArchive_{02-04-2025}_{01-15-20}\комплектующие\Arduino\arduinoUnoCH340_USB-B_v2_2.a3d | C:\Users\пользователь\Desktop\работа\хахатон\итог\комплект файлов (комплектовщик Компас-3D + STEP сборка)\комплектующие\Arduino\arduinoUnoCH340_USB-B_v2_2.a3d
C:\Users\пользователь\Desktop\работа\хахатон\_KDPackageArchive_{02-04-2025}_{01-15-20}\комплектующие\Arduino\arduinoUnoCH340_USB-B_v2_3.a3d | C:\Users\пользователь\Desktop\работа\хахатон\итог\комплект файлов (комплектовщик Компас-3D + STEP сборка)\комплектующие\Arduino\arduinoUnoCH340_USB-B_v2_3.a3d
C:\Users\пользователь\Desktop\работа\хахатон\_KDPackageArchive_{02-04-2025}_{01-15-20}\комплектующие\Arduino\arduinoUnoCH340_USB-B_v2_4.a3d | C:\Users\пользователь\Desktop\работа\хахатон\итог\комплект файлов (комплектовщик Компас-3D + STEP сборка)\комплектующие\Arduino\arduinoUnoCH340_USB-B_v2_4.a3d
C:\Users\пользователь\Desktop\работа\хахатон\_KDPackageArchive_{02-04-2025}_{01-15-20}\комплектующие\Arduino\arduinoUnoCH340_USB-B_v2_5.a3d | C:\Users\пользователь\Desktop\работа\хахатон\итог\комплект файлов (комплектовщик Компас-3D + STEP сборка)\комплектующие\Arduino\arduinoUnoCH340_USB-B_v2_5.a3d
C:\Users\пользователь\Desktop\работа\хахатон\_KDPackageArchive_{02-04-2025}_{01-15-20}\комплектующие\Arduino\arduinoUnoCH340_USB-B_v2_6.a3d | C:\Users\пользователь\Desktop\работа\хахатон\итог\комплект файлов (комплектовщик Компас-3D + STEP сборка)\комплектующие\Arduino\arduinoUnoCH340_USB-B_v2_6.a3d
C:\Users\пользователь\Desktop\работа\хахатон\_KDPackageArchive_{02-04-2025}_{01-15-20}\комплектующие\Arduino\arduinoUnoCH340_USB-B_v2_7.a3d | C:\Users\пользователь\Desktop\работа\хахатон\итог\комплект файлов (комплектовщик Компас-3D + STEP сборка)\комплектующие\Arduino\arduinoUnoCH340_USB-B_v2_7.a3d
C:\Users\пользователь\Desktop\работа\хахатон\_KDPackageArchive_{02-04-2025}_{01-15-20}\комплектующие\Arduino\arduinoUnoCH340_USB-B_v2_8.a3d | C:\Users\пользователь\Desktop\работа\хахатон\итог\комплект файлов (комплектовщик Компас-3D + STEP сборка)\комплектующие\Arduino\arduinoUnoCH340_USB-B_v2_8.a3d
C:\Users\пользователь\Desktop\работа\хахатон\_KDPackageArchive_{02-04-2025}_{01-15-20}\комплектующие\Arduino\arduinoUnoCH340_USB-B_v2_9.a3d | C:\Users\пользователь\Desktop\работа\хахатон\итог\комплект файлов (комплектовщик Компас-3D + STEP сборка)\комплектующие\Arduino\arduinoUnoCH340_USB-B_v2_9.a3d
C:\Users\пользователь\Desktop\работа\хахатон\_KDPackageArchive_{02-04-2025}_{01-15-20}\комплектующие\Arduino\A-USBSB.m3d | C:\Users\пользователь\Desktop\работа\хахатон\итог\комплект файлов (комплектовщик Компас-3D + STEP сборка)\комплектующие\Arduino\A-USBSB.m3d
C:\Users\пользователь\Desktop\работа\хахатон\_KDPackageArchive_{02-04-2025}_{01-15-20}\комплектующие\Arduino\BarrelJack_Horizontal.m3d | C:\Users\пользователь\Desktop\работа\хахатон\итог\комплект файлов (комплектовщик Компас-3D + STEP сборка)\комплектующие\Arduino\BarrelJack_Horizontal.m3d
C:\Users\пользователь\Desktop\работа\хахатон\_KDPackageArchive_{02-04-2025}_{01-15-20}\комплектующие\Arduino\BarrelJack_Horizontal001.m3d | C:\Users\пользователь\Desktop\работа\хахатон\итог\комплект файлов (комплектовщик Компас-3D + STEP сборка)\комплектующие\Arduino\BarrelJack_Horizontal001.m3d
C:\Users\пользователь\Desktop\работа\хахатон\_KDPackageArchive_{02-04-2025}_{01-15-20}\комплектующие\Arduino\BarrelJack_Horizontal002.m3d | C:\Users\пользователь\Desktop\работа\хахатон\итог\комплект файлов (комплектовщик Компас-3D + STEP сборка)\комплектующие\Arduino\BarrelJack_Horizontal002.m3d
C:\Users\пользователь\Desktop\работа\хахатон\_KDPackageArchive_{02-04-2025}_{01-15-20}\комплектующие\Arduino\BarrelJack_Horizontal003.m3d | C:\Users\пользователь\Desktop\работа\хахатон\итог\комплект файлов (комплектовщик Компас-3D + STEP сборка)\комплектующие\Arduino\BarrelJack_Horizontal003.m3d
C:\Users\пользователь\Desktop\работа\хахатон\_KDPackageArchive_{02-04-2025}_{01-15-20}\комплектующие\Arduino\BarrelJack_Horizontal004.m3d | C:\Users\пользователь\Desktop\работа\хахатон\итог\комплект файлов (комплектовщик Компас-3D + STEP сборка)\комплектующие\Arduino\BarrelJack_Horizontal004.m3d
C:\Users\пользователь\Desktop\работа\хахатон\_KDPackageArchive_{02-04-2025}_{01-15-20}\комплектующие\Arduino\C_0603_1608Metric.m3d | C:\Users\пользователь\Desktop\работа\хахатон\итог\комплект файлов (комплектовщик Компас-3D + STEP сборка)\комплектующие\Arduino\C_0603_1608Metric.m3d
C:\Users\пользователь\Desktop\работа\хахатон\_KDPackageArchive_{02-04-2025}_{01-15-20}\комплектующие\Arduino\C_Elec_63x055.m3d | C:\Users\пользователь\Desktop\работа\хахатон\итог\комплект файлов (комплектовщик Компас-3D + STEP сборка)\комплектующие\Arduino\C_Elec_63x055.m3d
C:\Users\пользователь\Desktop\работа\хахатон\_KDPackageArchive_{02-04-2025}_{01-15-20}\комплектующие\Arduino\C_Elec_63x54.m3d | C:\Users\пользователь\Desktop\работа\хахатон\итог\комплект файлов (комплектовщик Компас-3D + STEP сборка)\комплектующие\Arduino\C_Elec_63x54.m3d
C:\Users\пользователь\Desktop\работа\хахатон\_KDPackageArchive_{02-04-2025}_{01-15-20}\комплектующие\Arduino\Corps.m3d | C:\Users\пользователь\Desktop\работа\хахатон\итог\комплект файлов (комплектовщик Компас-3D + STEP сборка)\комплектующие\Arduino\Corps.m3d
C:\Users\пользователь\Desktop\работа\хахатон\_KDPackageArchive_{02-04-2025}_{01-15-20}\комплектующие\Arduino\Crystal_SMD_HC49-SD.m3d | C:\Users\пользователь\Desktop\работа\хахатон\итог\комплект файлов (комплектовщик Компас-3D + STEP сборка)\комплектующие\Arduino\Crystal_SMD_HC49-SD.m3d
C:\Users\пользователь\Desktop\работа\хахатон\_KDPackageArchive_{02-04-2025}_{01-15-20}\комплектующие\Arduino\Crystal_SMD_HC49-SD001.m3d | C:\Users\пользователь\Desktop\работа\хахатон\итог\комплект файлов (комплектовщик Компас-3D + STEP сборка)\комплектующие\Arduino\Crystal_SMD_HC49-SD001.m3d
C:\Users\пользователь\Desktop\работа\хахатон\_KDPackageArchive_{02-04-2025}_{01-15-20}\комплектующие\Arduino\D_SMA.m3d | C:\Users\пользователь\Desktop\работа\хахатон\итог\комплект файлов (комплектовщик Компас-3D + STEP сборка)\комплектующие\Arduino\D_SMA.m3d
C:\Users\пользователь\Desktop\работа\хахатон\_KDPackageArchive_{02-04-2025}_{01-15-20}\комплектующие\Arduino\D_SOD_123.m3d | C:\Users\пользователь\Desktop\работа\хахатон\итог\комплект файлов (комплектовщик Компас-3D + STEP сборка)\комплектующие\Arduino\D_SOD_123.m3d
C:\Users\пользователь\Desktop\работа\хахатон\_KDPackageArchive_{02-04-2025}_{01-15-20}\комплектующие\Arduino\LED_0603_1608Metric_ON.m3d | C:\Users\пользователь\Desktop\работа\хахатон\итог\комплект файлов (комплектовщик Компас-3D + STEP сборка)\комплектующие\Arduino\LED_0603_1608Metric_ON.m3d
C:\Users\пользователь\Desktop\работа\хахатон\_KDPackageArchive_{02-04-2025}_{01-15-20}\комплектующие\Arduino\LQFP_32_7x7mm_P08mm.m3d | C:\Users\пользователь\Desktop\работа\хахатон\итог\комплект файлов (комплектовщик Компас-3D + STEP сборка)\комплектующие\Arduino\LQFP_32_7x7mm_P08mm.m3d
C:\Users\пользователь\Desktop\работа\хахатон\_KDPackageArchive_{02-04-2025}_{01-15-20}\комплектующие\Arduino\PinHeader_2x03_P254mm_Vertical.m3d | C:\Users\пользователь\Desktop\работа\хахатон\итог\комплект файлов (комплектовщик Компас-3D + STEP сборка)\комплектующие\Arduino\PinHeader_2x03_P254mm_Vertical.m3d
C:\Users\пользователь\Desktop\работа\хахатон\_KDPackageArchive_{02-04-2025}_{01-15-20}\комплектующие\Arduino\PinSocket_1x06_P2.54mm_Vertical.m3d | C:\Users\пользователь\Desktop\работа\хахатон\итог\комплект файлов (комплектовщик Компас-3D + STEP сборка)\комплектующие\Arduino\PinSocket_1x06_P2.54mm_Vertical.m3d
C:\Users\пользователь\Desktop\работа\хахатон\_KDPackageArchive_{02-04-2025}_{01-15-20}\комплектующие\Arduino\PinSocket_1x08_P2.54mm_Vertical.m3d | C:\Users\пользователь\Desktop\работа\хахатон\итог\комплект файлов (комплектовщик Компас-3D + STEP сборка)\комплектующие\Arduino\PinSocket_1x08_P2.54mm_Vertical.m3d
C:\Users\пользователь\Desktop\работа\хахатон\_KDPackageArchive_{02-04-2025}_{01-15-20}\комплектующие\Arduino\PinSocket_1x10_P2.54mm_Vertical.m3d | C:\Users\пользователь\Desktop\работа\хахатон\итог\комплект файлов (комплектовщик Компас-3D + STEP сборка)\комплектующие\Arduino\PinSocket_1x10_P2.54mm_Vertical.m3d
C:\Users\пользователь\Desktop\работа\хахатон\_KDPackageArchive_{02-04-2025}_{01-15-20}\комплектующие\Arduino\R_0603_1608Metric.m3d | C:\Users\пользователь\Desktop\работа\хахатон\итог\комплект файлов (комплектовщик Компас-3D + STEP сборка)\комплектующие\Arduino\R_0603_1608Metric.m3d
C:\Users\пользователь\Desktop\работа\хахатон\_KDPackageArchive_{02-04-2025}_{01-15-20}\комплектующие\Arduino\RedButton.m3d | C:\Users\пользователь\Desktop\работа\хахатон\итог\комплект файлов (комплектовщик Компас-3D + STEP сборка)\комплектующие\Arduino\RedButton.m3d
C:\Users\пользователь\Desktop\работа\хахатон\_KDPackageArchive_{02-04-2025}_{01-15-20}\комплектующие\Arduino\SOIC_16_39x99mm_P127mm.m3d | C:\Users\пользователь\Desktop\работа\хахатон\итог\комплект файлов (комплектовщик Компас-3D + STEP сборка)\комплектующие\Arduino\SOIC_16_39x99mm_P127mm.m3d
C:\Users\пользователь\Desktop\работа\хахатон\_KDPackageArchive_{02-04-2025}_{01-15-20}\комплектующие\Arduino\SOIC_8_1EP_39x49mm_P127mm.m3d | C:\Users\пользователь\Desktop\работа\хахатон\итог\комплект файлов (комплектовщик Компас-3D + STEP сборка)\комплектующие\Arduino\SOIC_8_1EP_39x49mm_P127mm.m3d
C:\Users\пользователь\Desktop\работа\хахатон\_KDPackageArchive_{02-04-2025}_{01-15-20}\комплектующие\Arduino\Solder001.m3d | C:\Users\пользователь\Desktop\работа\хахатон\итог\комплект файлов (комплектовщик Компас-3D + STEP сборка)\комплектующие\Arduino\Solder001.m3d
C:\Users\пользователь\Desktop\работа\хахатон\_KDPackageArchive_{02-04-2025}_{01-15-20}\комплектующие\Arduino\SOT_223.m3d | C:\Users\пользователь\Desktop\работа\хахатон\итог\комплект файлов (комплектовщик Компас-3D + STEP сборка)\комплектующие\Arduino\SOT_223.m3d
C:\Users\пользователь\Desktop\работа\хахатон\_KDPackageArchive_{02-04-2025}_{01-15-20}\комплектующие\Arduino\SOT_23_1.m3d | C:\Users\пользователь\Desktop\работа\хахатон\итог\комплект файлов (комплектовщик Компас-3D + STEP сборка)\комплектующие\Arduino\SOT_23_1.m3d
C:\Users\пользователь\Desktop\работа\хахатон\_KDPackageArchive_{02-04-2025}_{01-15-20}\комплектующие\Arduino\SOT_23_2.m3d | C:\Users\пользователь\Desktop\работа\хахатон\итог\комплект файлов (комплектовщик Компас-3D + STEP сборка)\комплектующие\Arduino\SOT_23_2.m3d
C:\Users\пользователь\Desktop\работа\хахатон\_KDPackageArchive_{02-04-2025}_{01-15-20}\комплектующие\Arduino\Text_UNO.m3d | C:\Users\пользователь\Desktop\работа\хахатон\итог\комплект файлов (комплектовщик Компас-3D + STEP сборка)\комплектующие\Arduino\Text_UNO.m3d
C:\Users\пользователь\Desktop\работа\хахатон\_KDPackageArchive_{02-04-2025}_{01-15-20}\комплектующие\Arduino\trou001.m3d | C:\Users\пользователь\Desktop\работа\хахатон\итог\комплект файлов (комплектовщик Компас-3D + STEP сборка)\комплектующие\Arduino\trou001.m3d
C:\Users\пользователь\Desktop\работа\хахатон\_KDPackageArchive_{02-04-2025}_{01-15-20}\комплектующие\Arduino\trou002.m3d | C:\Users\пользователь\Desktop\работа\хахатон\итог\комплект файлов (комплектовщик Компас-3D + STEP сборка)\комплектующие\Arduino\trou002.m3d
C:\Users\пользователь\Desktop\работа\хахатон\_KDPackageArchive_{02-04-2025}_{01-15-20}\комплектующие\Arduino\trou003.m3d | C:\Users\пользователь\Desktop\работа\хахатон\итог\комплект файлов (комплектовщик Компас-3D + STEP сборка)\комплектующие\Arduino\trou003.m3d
C:\Users\пользователь\Desktop\работа\хахатон\_KDPackageArchive_{02-04-2025}_{01-15-20}\комплектующие\Arduino\trou004.m3d | C:\Users\пользователь\Desktop\работа\хахатон\итог\комплект файлов (комплектовщик Компас-3D + STEP сборка)\комплектующие\Arduino\trou004.m3d
C:\Users\пользователь\Desktop\работа\хахатон\_KDPackageArchive_{02-04-2025}_{01-15-20}\комплектующие\Arduino\trou005.m3d | C:\Users\пользователь\Desktop\работа\хахатон\итог\комплект файлов (комплектовщик Компас-3D + STEP сборка)\комплектующие\Arduino\trou005.m3d
C:\Users\пользователь\Desktop\работа\хахатон\_KDPackageArchive_{02-04-2025}_{01-15-20}\комплектующие\Arduino\trou006.m3d | C:\Users\пользователь\Desktop\работа\хахатон\итог\комплект файлов (комплектовщик Компас-3D + STEP сборка)\комплектующие\Arduino\trou006.m3d
C:\Users\пользователь\Desktop\работа\хахатон\_KDPackageArchive_{02-04-2025}_{01-15-20}\комплектующие\Arduino\trou007.m3d | C:\Users\пользователь\Desktop\работа\хахатон\итог\комплект файлов (комплектовщик Компас-3D + STEP сборка)\комплектующие\Arduino\trou007.m3d
C:\Users\пользователь\Desktop\работа\хахатон\_KDPackageArchive_{02-04-2025}_{01-15-20}\комплектующие\L298N\L298N Motor Driver.m3d | C:\Users\пользователь\Desktop\работа\хахатон\итог\комплект файлов (комплектовщик Компас-3D + STEP сборка)\комплектующие\L298N\L298N Motor Driver.m3d
C:\Users\пользователь\Desktop\работа\хахатон\_KDPackageArchive_{02-04-2025}_{01-15-20}\Комплектующие\MPU 6050\MPU6050 v2.m3d | C:\Users\пользователь\Desktop\работа\хахатон\итог\комплект файлов (комплектовщик Компас-3D + STEP сборка)\Комплектующие\MPU 6050\MPU6050 v2.m3d
C:\Users\пользователь\Desktop\работа\хахатон\_KDPackageArchive_{02-04-2025}_{01-15-20}\Комплектующие\MPU 6050\Опора для MPU 6050.m3d | C:\Users\пользователь\Desktop\работа\хахатон\итог\комплект файлов (комплектовщик Компас-3D + STEP сборка)\Комплектующие\MPU 6050\Опора для MPU 6050.m3d
C:\Users\пользователь\Desktop\работа\хахатон\_KDPackageArchive_{02-04-2025}_{01-15-20}\Комплектующие\MPU 6050\Сборка MPU 6050.a3d | C:\Users\пользователь\Desktop\работа\хахатон\итог\комплект файлов (комплектовщик Компас-3D + STEP сборка)\Комплектующие\MPU 6050\Сборка MPU 6050.a3d
C:\Users\пользователь\Desktop\работа\хахатон\_KDPackageArchive_{02-04-2025}_{01-15-20}\комплектующие\Raspberry Pi 4B\full raspberry pi 4 upgrade cooling.a3d | C:\Users\пользователь\Desktop\работа\хахатон\итог\комплект файлов (комплектовщик Компас-3D + STEP сборка)\комплектующие\Raspberry Pi 4B\full raspberry pi 4 upgrade cooling.a3d
C:\Users\пользователь\Desktop\работа\хахатон\_KDPackageArchive_{02-04-2025}_{01-15-20}\комплектующие\Raspberry Pi 4B\вентилятор v6.m3d | C:\Users\пользователь\Desktop\работа\хахатон\итог\комплект файлов (комплектовщик Компас-3D + STEP сборка)\комплектующие\Raspberry Pi 4B\вентилятор v6.m3d
C:\Users\пользователь\Desktop\работа\хахатон\_KDPackageArchive_{02-04-2025}_{01-15-20}\комплектующие\Raspberry Pi 4B\радиатор верх v21.m3d | C:\Users\пользователь\Desktop\работа\хахатон\итог\комплект файлов (комплектовщик Компас-3D + STEP сборка)\комплектующие\Raspberry Pi 4B\радиатор верх v21.m3d
C:\Users\пользователь\Desktop\работа\хахатон\_KDPackageArchive_{02-04-2025}_{01-15-20}\комплектующие\Raspberry Pi 4B\радиатор низ v4.m3d | C:\Users\пользователь\Desktop\работа\хахатон\итог\комплект файлов (комплектовщик Компас-3D + STEP сборка)\комплектующие\Raspberry Pi 4B\радиатор низ v4.m3d
C:\Users\пользователь\Desktop\работа\хахатон\_KDPackageArchive_{02-04-2025}_{01-15-20}\комплектующие\RPLidar\base.m3d | C:\Users\пользователь\Desktop\работа\хахатон\итог\комплект файлов (комплектовщик Компас-3D + STEP сборка)\комплектующие\RPLidar\base.m3d
C:\Users\пользователь\Desktop\работа\хахатон\_KDPackageArchive_{02-04-2025}_{01-15-20}\комплектующие\RPLidar\bottom-lid.m3d | C:\Users\пользователь\Desktop\работа\хахатон\итог\комплект файлов (комплектовщик Компас-3D + STEP сборка)\комплектующие\RPLidar\bottom-lid.m3d
C:\Users\пользователь\Desktop\работа\хахатон\_KDPackageArchive_{02-04-2025}_{01-15-20}\комплектующие\RPLidar\connector-1_25-3pin.m3d | C:\Users\пользователь\Desktop\работа\хахатон\итог\комплект файлов (комплектовщик Компас-3D + STEP сборка)\комплектующие\RPLidar\connector-1_25-3pin.m3d
C:\Users\пользователь\Desktop\работа\хахатон\_KDPackageArchive_{02-04-2025}_{01-15-20}\комплектующие\RPLidar\connector-1_25-4pin.m3d | C:\Users\пользователь\Desktop\работа\хахатон\итог\комплект файлов (комплектовщик Компас-3D + STEP сборка)\комплектующие\RPLidar\connector-1_25-4pin.m3d
C:\Users\пользователь\Desktop\работа\хахатон\_KDPackageArchive_{02-04-2025}_{01-15-20}\комплектующие\RPLidar\detector.m3d | C:\Users\пользователь\Desktop\работа\хахатон\итог\комплект файлов (комплектовщик Компас-3D + STEP сборка)\комплектующие\RPLidar\detector.m3d
C:\Users\пользователь\Desktop\работа\хахатон\_KDPackageArchive_{02-04-2025}_{01-15-20}\комплектующие\RPLidar\detector-mount.m3d | C:\Users\пользователь\Desktop\работа\хахатон\итог\комплект файлов (комплектовщик Компас-3D + STEP сборка)\комплектующие\RPLidar\detector-mount.m3d
C:\Users\пользователь\Desktop\работа\хахатон\_KDPackageArchive_{02-04-2025}_{01-15-20}\комплектующие\RPLidar\head.m3d | C:\Users\пользователь\Desktop\работа\хахатон\итог\комплект файлов (комплектовщик Компас-3D + STEP сборка)\комплектующие\RPLidar\head.m3d
C:\Users\пользователь\Desktop\работа\хахатон\_KDPackageArchive_{02-04-2025}_{01-15-20}\комплектующие\RPLidar\head-base.m3d | C:\Users\пользователь\Desktop\работа\хахатон\итог\комплект файлов (комплектовщик Компас-3D + STEP сборка)\комплектующие\RPLidar\head-base.m3d
C:\Users\пользователь\Desktop\работа\хахатон\_KDPackageArchive_{02-04-2025}_{01-15-20}\комплектующие\RPLidar\laser.m3d | C:\Users\пользователь\Desktop\работа\хахатон\итог\комплект файлов (комплектовщик Компас-3D + STEP сборка)\комплектующие\RPLidar\laser.m3d
C:\Users\пользователь\Desktop\работа\хахатон\_KDPackageArchive_{02-04-2025}_{01-15-20}\комплектующие\RPLidar\laser-mount.m3d | C:\Users\пользователь\Desktop\работа\хахатон\итог\комплект файлов (комплектовщик Компас-3D + STEP сборка)\комплектующие\RPLidar\laser-mount.m3d
C:\Users\пользователь\Desktop\работа\хахатон\_KDPackageArchive_{02-04-2025}_{01-15-20}\комплектующие\RPLidar\motherboard.m3d | C:\Users\пользователь\Desktop\работа\хахатон\итог\комплект файлов (комплектовщик Компас-3D + STEP сборка)\комплектующие\RPLidar\motherboard.m3d
C:\Users\пользователь\Desktop\работа\хахатон\_KDPackageArchive_{02-04-2025}_{01-15-20}\комплектующие\RPLidar\motor.m3d | C:\Users\пользователь\Desktop\работа\хахатон\итог\комплект файлов (комплектовщик Компас-3D + STEP сборка)\комплектующие\RPLidar\motor.m3d
C:\Users\пользователь\Desktop\работа\хахатон\_KDPackageArchive_{02-04-2025}_{01-15-20}\комплектующие\RPLidar\motor-board.m3d | C:\Users\пользователь\Desktop\работа\хахатон\итог\комплект файлов (комплектовщик Компас-3D + STEP сборка)\комплектующие\RPLidar\motor-board.m3d
C:\Users\пользователь\Desktop\работа\хахатон\_KDPackageArchive_{02-04-2025}_{01-15-20}\комплектующие\RPLidar\RP-lidar-A1.a3d | C:\Users\пользователь\Desktop\работа\хахатон\итог\комплект файлов (комплектовщик Компас-3D + STEP сборка)\комплектующие\RPLidar\RP-lidar-A1.a3d
C:\Users\пользователь\Desktop\работа\хахатон\_KDPackageArchive_{02-04-2025}_{01-15-20}\комплектующие\RPLidar\rubber.m3d | C:\Users\пользователь\Desktop\работа\хахатон\итог\комплект файлов (комплектовщик Компас-3D + STEP сборка)\комплектующие\RPLidar\rubber.m3d
C:\Users\пользователь\Desktop\работа\хахатон\_KDPackageArchive_{02-04-2025}_{01-15-20}\комплектующие\RPLidar\wheel.m3d | C:\Users\пользователь\Desktop\работа\хахатон\итог\комплект файлов (комплектовщик Компас-3D + STEP сборка)\комплектующие\RPLidar\wheel.m3d
C:\Users\пользователь\Desktop\работа\хахатон\_KDPackageArchive_{02-04-2025}_{01-15-20}\комплектующие\RPLidar\Woodscrews_GB_TYPE136 M2X6-N.m3d | C:\Users\пользователь\Desktop\работа\хахатон\итог\комплект файлов (комплектовщик Компас-3D + STEP сборка)\комплектующие\RPLidar\Woodscrews_GB_TYPE136 M2X6-N.m3d
C:\Users\пользователь\Desktop\работа\хахатон\_KDPackageArchive_{02-04-2025}_{01-15-20}\комплектующие\аккумулятор.m3d | C:\Users\пользователь\Desktop\работа\хахатон\итог\комплект файлов (комплектовщик Компас-3D + STEP сборка)\комплектующие\аккумулятор.m3d
C:\Users\пользователь\Desktop\работа\хахатон\_KDPackageArchive_{02-04-2025}_{01-15-20}\комплектующие\мотор\JGY-370.m3d | C:\Users\пользователь\Desktop\работа\хахатон\итог\комплект файлов (комплектовщик Компас-3D + STEP сборка)\комплектующие\мотор\JGY-370.m3d
C:\Users\пользователь\Desktop\работа\хахатон\_KDPackageArchive_{02-04-2025}_{01-15-20}\комплектующие\Понижающий преобразователь.m3d | C:\Users\пользователь\Desktop\работа\хахатон\итог\комплект файлов (комплектовщик Компас-3D + STEP сборка)\комплектующие\Понижающий преобразователь.m3d
C:\Users\пользователь\Desktop\работа\хахатон\_KDPackageArchive_{02-04-2025}_{01-15-20}\Комплектующие\Шаровая опора\Опора для шаровой опоры.m3d | C:\Users\пользователь\Desktop\работа\хахатон\итог\комплект файлов (комплектовщик Компас-3D + STEP сборка)\Комплектующие\Шаровая опора\Опора для шаровой опоры.m3d
C:\Users\пользователь\Desktop\работа\хахатон\_KDPackageArchive_{02-04-2025}_{01-15-20}\Комплектующие\Шаровая опора\Шаровая опора.m3d | C:\Users\пользователь\Desktop\работа\хахатон\итог\комплект файлов (комплектовщик Компас-3D + STEP сборка)\Комплектующие\Шаровая опора\Шаровая опора.m3d
C:\Users\пользователь\Desktop\работа\хахатон\_KDPackageArchive_{02-04-2025}_{01-15-20}\Корпус\Второй этаж.m3d | C:\Users\пользователь\Desktop\работа\хахатон\итог\комплект файлов (комплектовщик Компас-3D + STEP сборка)\Корпус\Второй этаж.m3d
C:\Users\пользователь\Desktop\работа\хахатон\_KDPackageArchive_{02-04-2025}_{01-15-20}\Корпус\Первый этаж.m3d | C:\Users\пользователь\Desktop\работа\хахатон\итог\комплект файлов (комплектовщик Компас-3D + STEP сборка)\Корпус\Первый этаж.m3d
C:\Users\пользователь\Desktop\работа\хахатон\_KDPackageArchive_{02-04-2025}_{01-15-20}\Корпус\Стенки корпуса.m3d | C:\Users\пользователь\Desktop\работа\хахатон\итог\комплект файлов (комплектовщик Компас-3D + STEP сборка)\Корпус\Стенки корпуса.m3d
C:\Users\пользователь\Desktop\работа\хахатон\_KDPackageArchive_{02-04-2025}_{01-15-20}\Робот.a3d | C:\Users\пользователь\Desktop\работа\хахатон\итог\комплект файлов (комплектовщик Компас-3D + STEP сборка)\Робот.a3d
C:\Users\пользователь\Desktop\работа\хахатон\_KDPackageArchive_{02-04-2025}_{01-15-20}\Сборка колеса\Колесо.m3d | C:\Users\пользователь\Desktop\работа\хахатон\итог\комплект файлов (комплектовщик Компас-3D + STEP сборка)\Сборка колеса\Колесо.m3d
C:\Users\пользователь\Desktop\работа\хахатон\_KDPackageArchive_{02-04-2025}_{01-15-20}\Сборка колеса\Сборка колеса.a3d | C:\Users\пользователь\Desktop\работа\хахатон\итог\комплект файлов (комплектовщик Компас-3D + STEP сборка)\Сборка колеса\Сборка колеса.a3d
C:\Users\пользователь\Desktop\работа\хахатон\_KDPackageArchive_{02-04-2025}_{01-15-20}\Сборка колеса\Фланец.m3d | C:\Users\пользователь\Desktop\работа\хахатон\итог\комплект файлов (комплектовщик Компас-3D + STEP сборка)\Сборка колеса\Фланец.m3d
C:\Users\пользователь\Desktop\работа\хахатон\_KDPackageArchive_{02-04-2025}_{01-15-20}\скоба мотора левая.m3d | C:\Users\пользователь\Desktop\работа\хахатон\итог\комплект файлов (комплектовщик Компас-3D + STEP сборка)\скоба мотора левая.m3d
C:\Users\пользователь\Desktop\работа\хахатон\_KDPackageArchive_{02-04-2025}_{01-15-20}\скоба мотора правая.m3d | C:\Users\пользователь\Desktop\работа\хахатон\итог\комплект файлов (комплектовщик Компас-3D + STEP сборка)\скоба мотора правая.m3d
C:\Users\пользователь\Desktop\работа\хахатон\_KDPackageArchive_{02-04-2025}_{01-15-20}\Стойка для Arduino.m3d | C:\Users\пользователь\Desktop\работа\хахатон\итог\комплект файлов (комплектовщик Компас-3D + STEP сборка)\Стойка для Arduino.m3d
C:\Users\пользователь\Desktop\работа\хахатон\_KDPackageArchive_{02-04-2025}_{01-15-20}\Стойка для RPLidar.m3d | C:\Users\пользователь\Desktop\работа\хахатон\итог\комплект файлов (комплектовщик Компас-3D + STEP сборка)\Стойка для RPLidar.m3d

### Прочие файлы, добавленные в комплект:

Исходное имя | Имя в комплекте
C:\Program Files\ASCON\KOMPAS-3D v23\Sys\GRAPHIC.LYT | C:\Users\пользователь\Desktop\работа\хахатон\итог\комплект файлов (комплектовщик Компас-3D + STEP сборка)\_Sys\GRAPHIC.LYT
C:\Program Files\ASCON\KOMPAS-3D v23\Sys\Spc.lat | C:\Users\пользователь\Desktop\работа\хахатон\итог\комплект файлов (комплектовщик Компас-3D + STEP сборка)\_Sys\Spc.lat

### Исходные данные комплектовки:

Основные документы комплекта: | C:\Users\пользователь\Desktop\работа\хахатон\_KDPackageArchive_{02-04-2025}_{01-15-20}\Робот.a3d
Папки для поиска документов, которые ссылаются на документы комплекта: | C:\Users\пользователь\Desktop\работа\хахатон\_KDPackageArchive_{02-04-2025}_{01-15-20}

Настройки:
Шаблон именования файлов КОМПАС-документов в комплекте: | <Исходное имя файла>
Переименовывать файлы внешних документов: | Откл.
Сохранять структуру папок: | Вкл.
Обрабатывать ссылки в объектах спецификации: | Откл.
Транслитерировать имена файлов в комплекте: | Откл.

Дополнительно включать в комплект:
Внешние документы | Вкл.
Вспомогательные файлы | Вкл.
Источники копий геометрии | Вкл.
Источники компоновочной геометрии | Вкл.

Параметры размещения:
Размещать в подпапке:
Группировать по папке-источнику: | Вкл.
Префикс имен групп: | _
Папка комплекта: | C:\Users\пользователь\Desktop\работа\хахатон\итог\комплект файлов (комплектовщик Компас-3D + STEP сборка)

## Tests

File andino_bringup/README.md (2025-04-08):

# MEPhI_ROS2_drone_bringup

## Описание
Здесь содержатся основные файлы запуска для старта всех соответствующих драйверов и нод, которые будут использоваться в роботе. Также добавлены некоторые конфигурационные файлы для настройки нод, хранящиеся в папке `config`.

## Launch Files

### Главный файл запуска всего проекта

Основным файлом запуска является файл `andino_robot.launch.py`. Этот файл запускает все необходимые ноды для работы MEPhI_ROS2_drone.

Он включает:

- `andino_description.launch.py`: файл для загрузки 3D модели робота из `urdf` описания
- `andino_control.launch.py`: файл для запуска нод и драйверов пакета `ros2_control`
- `rplidar.launch.py`: файл для запуска драйверов `RPLIDAR A1`, подключенного к роботу

### Другие launch files

Эти файлы запуска включены на тот случай, если вы захотите управлять роботом другими способами или визуализировать информацию:

- `rosbag_record.launch.py`: выполняет команду `ros2 bag record` для сохранения файла `.bag` с указанными топиками. Если конкретные топики не указаны, программа запишет их все
- `rviz.launch.py`: запускает инструмент визуализации `RViz` с конфигурацией `andino.rviz` по умолчанию, чтобы иметь возможность визуализировать 3D-модель робота и информацию из топиков
- `teleop_keyboard.launch.py`: позволяет вам управлять роботом с помощью клавиатуры, используя пакет `teleop_twist_keyboard`

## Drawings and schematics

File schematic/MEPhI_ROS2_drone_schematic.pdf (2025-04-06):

L298N

# Raspberry Pi 4

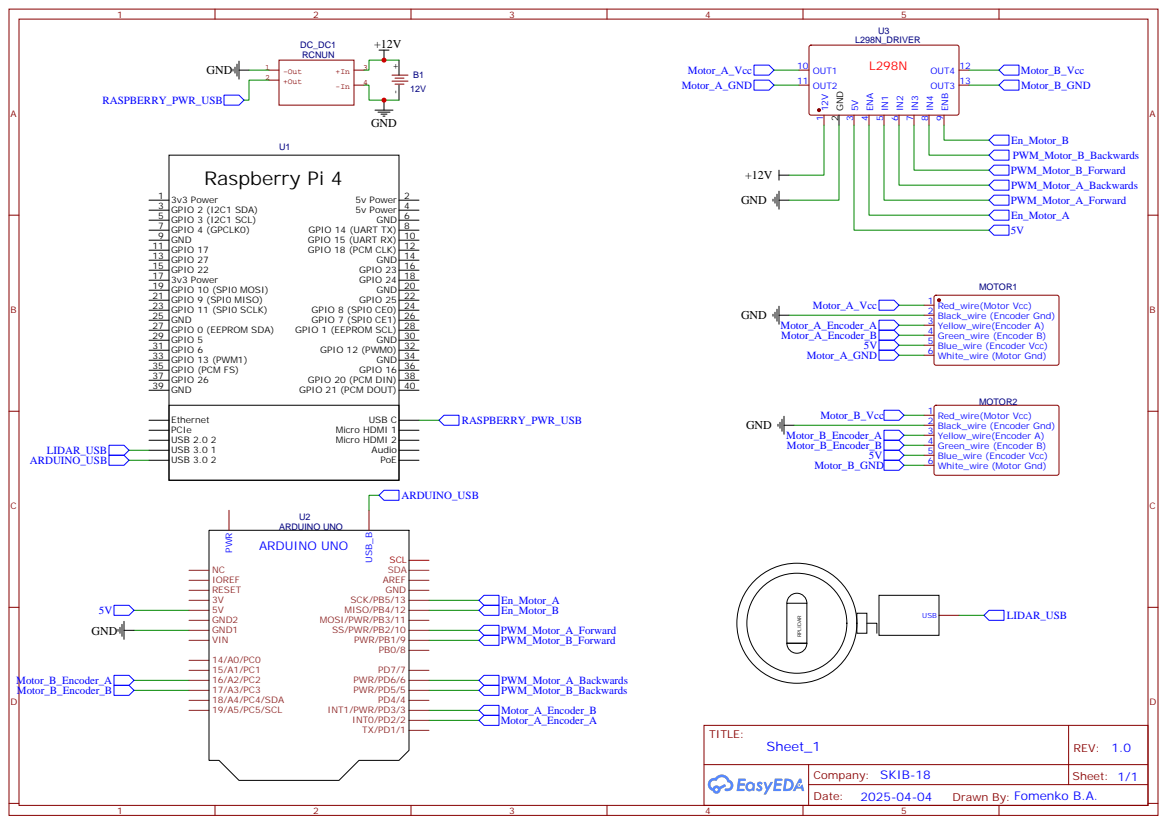
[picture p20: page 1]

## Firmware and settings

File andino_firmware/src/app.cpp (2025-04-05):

#include "app.h"

#include <Adafruit_BNO055.h>
#include <Adafruit_Sensor.h>
#include <Arduino.h>
#include <Wire.h>
#include <utility/imumaths.h>

#include "commands.h"
#include "constants.h"
#include "digital_out_arduino.h"
#include "encoder.h"
#include "hw.h"
#include "interrupt_in_arduino.h"
#include "motor.h"
#include "pid.h"
#include "pwm_out_arduino.h"
#include "serial_stream_arduino.h"
#include "shell.h"

namespace andino {

SerialStreamArduino App::serial_stream_;

Shell App::shell_;

DigitalOutArduino App::left_motor_enable_digital_out_(Hw::kLeftMotorEnableGpioPin);
PwmOutArduino App::left_motor_forward_pwm_out_(Hw::kLeftMotorForwardGpioPin);
PwmOutArduino App::left_motor_backward_pwm_out_(Hw::kLeftMotorBackwardGpioPin);
Motor App::left_motor_(&left_motor_enable_digital_out_, &left_motor_forward_pwm_out_,
                       &left_motor_backward_pwm_out_);

DigitalOutArduino App::right_motor_enable_digital_out_(Hw::kRightMotorEnableGpioPin);
PwmOutArduino App::right_motor_forward_pwm_out_(Hw::kRightMotorForwardGpioPin);
PwmOutArduino App::right_motor_backward_pwm_out_(Hw::kRightMotorBackwardGpioPin);
Motor App::right_motor_(&right_motor_enable_digital_out_, &right_motor_forward_pwm_out_,
                        &right_motor_backward_pwm_out_);

InterruptInArduino App::left_encoder_channel_a_interrupt_in_(Hw::kLeftEncoderChannelAGpioPin);
InterruptInArduino App::left_encoder_channel_b_interrupt_in_(Hw::kLeftEncoderChannelBGpioPin);
Encoder App::left_encoder_(&left_encoder_channel_a_interrupt_in_,
                           &left_encoder_channel_b_interrupt_in_);

InterruptInArduino App::right_encoder_channel_a_interrupt_in_(Hw::kRightEncoderChannelAGpioPin);
InterruptInArduino App::right_encoder_channel_b_interrupt_in_(Hw::kRightEncoderChannelBGpioPin);
Encoder App::right_encoder_(&right_encoder_channel_a_interrupt_in_,
                            &right_encoder_channel_b_interrupt_in_);

Pid App::left_pid_controller_(Constants::kPidKp, Constants::kPidKd, Constants::kPidKi,
                              Constants::kPidKo, -Constants::kPwmMax, Constants::kPwmMax);
Pid App::right_pid_controller_(Constants::kPidKp, Constants::kPidKd, Constants::kPidKi,
                               Constants::kPidKo, -Constants::kPwmMax, Constants::kPwmMax);

unsigned long App::last_pid_computation_{0};

unsigned long App::last_set_motors_speed_cmd_{0};

bool App::is_imu_connected{false};

Adafruit_BNO055 App::bno055_imu_{/*sensorID=*/55, BNO055_ADDRESS_A, &Wire};

void App::setup() {
  // Required by Arduino libraries to work.
  init();

  serial_stream_.begin(Constants::kBaudrate);

  left_encoder_.begin();
  right_encoder_.begin();

  left_motor_.begin();
  left_motor_.enable(true);
  right_motor_.begin();
  right_motor_.enable(true);

  left_pid_controller_.reset(left_encoder_.read());
  right_pid_controller_.reset(right_encoder_.read());

  // Initialize command shell.
  shell_.set_serial_stream(&serial_stream_);
  shell_.set_default_callback(cmd_unknown_cb);
  shell_.register_command(Commands::kReadAnalogGpio, cmd_read_analog_gpio_cb);
  shell_.register_command(Commands::kReadDigitalGpio, cmd_read_digital_gpio_cb);
  shell_.register_command(Commands::kReadEncoders, cmd_read_encoders_cb);
  shell_.register_command(Commands::kResetEncoders, cmd_reset_encoders_cb);
  shell_.register_command(Commands::kSetMotorsSpeed, cmd_set_motors_speed_cb);
  shell_.register_command(Commands::kSetMotorsPwm, cmd_set_motors_pwm_cb);
  shell_.register_command(Commands::kSetPidsTuningGains, cmd_set_pid_tuning_gains_cb);
  shell_.register_command(Commands::kGetIsImuConnected, cmd_get_is_imu_connected_cb);
  shell_.register_command(Commands::kReadEncodersAndImu, cmd_read_encoders_and_imu_cb);

  // Initialize IMU sensor.
  if (bno055_imu_.begin()) {
    bno055_imu_.setExtCrystalUse(true);
    is_imu_connected = true;
  }
}

void App::loop() {
  
  // Process command prompt input.
  shell_.process_input();

  // Compute PID output at the configured rate.
  if ((millis() - last_pid_computation_) > Constants::kPidPeriod) {
    last_pid_computation_ = millis();
    adjust_motors_speed();
  }

  // Stop the motors if auto-stop interval has been reached.
  if ((millis() - last_set_motors_speed_cmd_) > Constants::kAutoStopWindow) {
    last_set_motors_speed_cmd_ = millis();
    stop_motors();
  }

  // Required by Arduino libraries to work.
  if (serialEventRun) {
    serialEventRun();
  }
}

void App::adjust_motors_speed() {
  int left_motor_speed = 0;
  int right_motor_speed = 0;
  left_pid_controller_.compute(left_encoder_.read(), left_motor_speed);
  right_pid_controller_.compute(right_encoder_.read(), right_motor_speed);
  if (left_pid_controller_.enabled()) {
    left_motor_.set_speed(left_motor_speed);
  }
  if (right_pid_controller_.enabled()) {
    right_motor_.set_speed(right_motor_speed);
  }
}

void App::stop_motors() {
  left_motor_.set_speed(0);
  right_motor_.set_speed(0);
  left_pid_controller_.disable();
  right_pid_controller_.disable();
}

void App::cmd_unknown_cb(int, char**) { Serial.println("Unknown command."); }

void App::cmd_read_analog_gpio_cb(int argc, char** argv) {
  if (argc < 2) {
    return;
  }

  const int pin = atoi(argv[1]);
  Serial.println(analogRead(pin));
}

void App::cmd_read_digital_gpio_cb(int argc, char** argv) {
  if (argc < 2) {
    return;
  }

  const int pin = atoi(argv[1]);
  Serial.println(digitalRead(pin));
}

void App::cmd_read_encoders_cb(int, char**) {
  Serial.print(left_encoder_.read());
  Serial.print(" ");
  Serial.println(right_encoder_.read());
}

void App::cmd_reset_encoders_cb(int, char**) {
  left_encoder_.reset();
  right_encoder_.reset();
  left_pid_controller_.reset(left_encoder_.read());
  right_pid_controller_.reset(right_encoder_.read());
  Serial.println("OK");
}

void App::cmd_set_motors_speed_cb(int argc, char** argv) {
  if (argc < 3) {
    return;
  }

  const int left_motor_speed = atoi(argv[1]);
  const int right_motor_speed = atoi(argv[2]);

  // Reset the auto stop timer.
  last_set_motors_speed_cmd_ = millis();
  if (left_motor_speed == 0 && right_motor_speed == 0) {
    left_motor_.set_speed(0);
    right_motor_.set_speed(0);
    left_pid_controller_.reset(left_encoder_.read());
    right_pid_controller_.reset(right_encoder_.read());
    left_pid_controller_.disable();
    right_pid_controller_.disable();
  } else {
    left_pid_controller_.enable();
    right_pid_controller_.enable();
  }

  // The target speeds are in ticks per second, so we need to convert them to ticks per
  // Constants::kPidRate.
  left_pid_controller_.set_setpoint(left_motor_speed / Constants::kPidRate);
  right_pid_controller_.set_setpoint(right_motor_speed / Constants::kPidRate);
  Serial.println("OK");
}
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

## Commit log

2025-03-24 The pin numbering for the new driver has changed
2025-04-05 Изменение прошивки для arduino uno
2025-04-05 Загрузка моделей, схем и доп описания
    [1-PLA-20%-Cкоба мотора левая.stl, 1-PLA-20%-Опора для MPU 6050.stl, 1-PLA-20%-Опора для шаровой опоры.stl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]
2025-04-06 Добавление описания к папкам проекта
2025-04-06 добавил электрическую схему
2025-04-06 добавил инструкцию по сборке схемы
2025-04-06 удаление инструкции
2025-04-06 добавил инструкцию
2025-04-06 дополнение ридмика
2025-04-06 Обновление документации
2025-04-06 обновление
2025-04-06 Доки для настройки
2025-04-06 Обновление README
2025-04-06 Обновление репозитория
2025-04-06 Обновление доков
2025-04-06 Последний (возможно))) коммит
2025-04-06 Добавление видео
2025-04-06 добавление видео (исправление бага)
2025-04-06 Добавление видео (теперь кажется работает)
2025-04-08 Обновление документации для MEPhI_ROS2_drone_bringup
2025-04-08 Обновление описания
2025-04-08 исправление конфига control
    [andino_controllers.yaml]
2025-04-08 Редактирование директорий
2025-04-08 удаление файла
2026-03-21 Create calibration script for camera calibration
2026-03-21 Update camera_calibration.py with new calibration content.
2026-03-21 Add calibration variables to ArucoMappingNode
    Initialize calibration variables and load calibration file.
2026-03-21 Add camera_undistort.py script
2026-03-21 Update default image path for camera calibration
